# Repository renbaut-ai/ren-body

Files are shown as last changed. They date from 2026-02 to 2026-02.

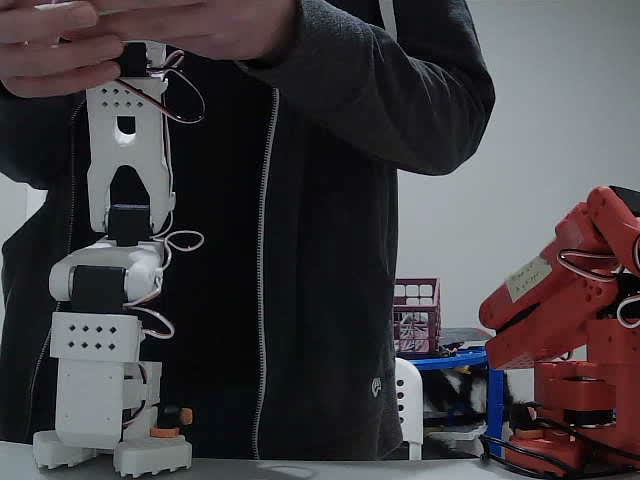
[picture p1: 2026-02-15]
training_data/demos/20260211_171234/frames/frame_0001.jpg

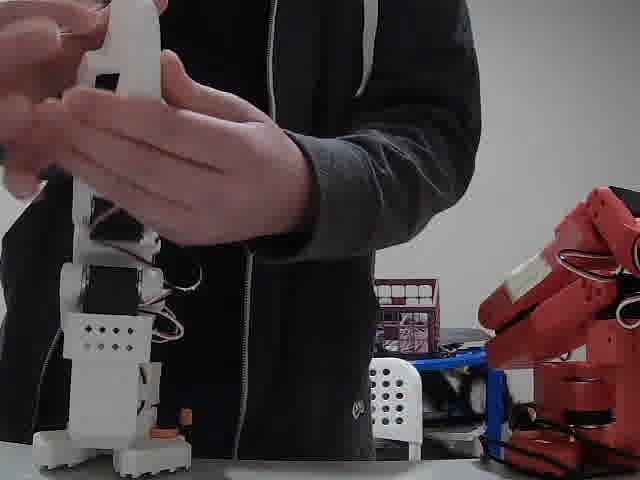
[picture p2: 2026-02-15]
training_data/demos/20260211_171234/frames/frame_0075.jpg

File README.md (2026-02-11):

# Ren Robot Body

Physical robot body design for the Ren AI assistant.

## Design Philosophy

- **Tracked mobile base** for stability and terrain handling (wheels/legs as future upgrade)
- **Articulated upper body** with dual SO-101 arms
- **Sensor head** with stereo depth camera and expression display
- **Mac Mini compute** for running the AI locally

## Quick Start (Blender)

1. Open Blender
2. Go to **Scripting** tab (top menu bar)
3. Click **Open** and select `ren_body_blender.py`
4. Click **Run Script** (▶ button)
5. Switch to **Layout** tab to view model
6. Set viewport shading to **Material Preview** for colors

## Quick Start (FreeCAD)

1. Open FreeCAD
2. Go to **Macro → Macros → Browse** and select `ren_body.py`
3. Run the macro to generate the parametric model
4. Adjust parameters at the top of the script to modify dimensions

## Files

| File | Description |
|---|---|
| `README.md` | This file |
| `PARTS_LIST.md` | Bill of materials with costs |
| `ASSEMBLY_GUIDE.md` | Step-by-step build instructions |
| `ren_body.py` | FreeCAD Python macro for parametric model |
| `ren_body_blender.py` | Blender Python script for 3D model |

## Key Dimensions

| Measurement | Value |
|---|---|
| Total height | 42" (1067mm) |
| Arm shoulder height | 34" (864mm) |
| Base footprint | 350mm × 300mm |
| Shoulder width | 280mm |

## Status

- [x] Initial design concept
- [x] Parts list draft
- [x] Basic FreeCAD model
- [ ] Detailed arm mounts (SO-101 specific)
- [ ] Track system selection
- [ ] Wiring routing
- [ ] Detailed head assembly
- [ ] Printable STL export

## Existing Hardware

- 2× SO-101 arms (marcus_agrippa_follower, marcus_agrippa_leader)
- Bambu A1 for 3D printing
- Mac Mini (planned compute)

---

*Project started: 2026-02-04*

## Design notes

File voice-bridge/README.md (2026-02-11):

# Ren Voice Bridge

Real-time voice communication between a Raspberry Pi (with earbuds) and Ren on the Mac Mini.

## Architecture

```
┌─────────────────────┐         ┌─────────────────────┐
│   Raspberry Pi      │         │     Mac Mini        │
│   (Codec Zero)      │         │                     │
├─────────────────────┤         ├─────────────────────┤
│ • Wired earbuds     │  HTTP   │ • Voice Server      │
│ • PTT button        │ ◄─────► │ • Whisper (STT)     │
│ • Record/Playback   │  :5555  │ • OpenClaw (Ren)    │
│                     │         │ • OpenAI TTS        │
└─────────────────────┘         └─────────────────────┘
```

## Flow

1. User presses PTT button
2. Pi records audio from mic
3. User releases button
4. Pi sends WAV to Mac Mini
5. Mac Mini transcribes with Whisper
6. Mac Mini sends text to OpenClaw (Ren)
7. Ren responds with text
8. Mac Mini converts to speech (OpenAI TTS)
9. Mac Mini sends audio back to Pi
10. Pi plays through earbuds

## Setup - Mac Mini (Server)

```bash
cd server

# Create venv
python3 -m venv .venv
source .venv/bin/activate

# Install deps
pip install -r requirements.txt

# Set OpenAI API key (for TTS)
export OPENAI_API_KEY="your-key"

# Run server
python voice_server.py
```

Server runs on port 5555 by default.

### Environment Variables

- `WHISPER_MODEL` - Whisper model size (tiny/base/small/medium) - default: base
- `OPENCLAW_API` - OpenClaw API endpoint - default: http://localhost:5001
- `TTS_VOICE` - OpenAI TTS voice (alloy/echo/fable/onyx/nova/shimmer) - default: alloy

## Setup - Raspberry Pi Zero

### Hardware

- Raspberry Pi Zero (W or 2W)
- Codec Zero I2S Audio HAT
- Wired earbuds with microphone
- Momentary push button for PTT

### Wiring

| Component | Pi GPIO |
|---|---|
| PTT Button | GPIO17 → GND |
| Status LED (optional) | GPIO27 |

The button uses internal pull-up, so wire between GPIO17 and GND.

### Software Setup

```bash
# Install system deps
sudo apt update
sudo apt install -y python3-pip python3-venv portaudio19-dev

# Clone/copy the pi-client directory
cd pi-client

# Create venv
python3 -m venv .venv
source .venv/bin/activate

# Install deps
pip install -r requirements.txt

# Configure server address
export VOICE_SERVER="http://macmini.local:5555"

# Test audio (record 3 sec and playback)
python voice_client.py --test

# Run client
python voice_client.py
```

### Codec Zero Setup

The Codec Zero HAT should be automatically detected. Configure ALSA:

```bash
# Check if detected
aplay -l
arecord -l

# Test recording
arecord -D default -f S16_LE -r 16000 -c 1 -d 3 test.wav
aplay test.wav
```

### Autostart on Boot

Create `/etc/systemd/system/voice-client.service`:

```ini
[Unit]
Description=Ren Voice Client
After=network.target

[Service]
Type=simple
User=pi
WorkingDirectory=/home/pi/voice-bridge/pi-client
Environment=VOICE_SERVER=http://macmini.local:5555
ExecStart=/home/pi/voice-bridge/pi-client/.venv/bin/python voice_client.py
Restart=always

[Install]
WantedBy=multi-user.target
```

Enable:
```bash
sudo systemctl enable voice-client
sudo systemctl start voice-client
```

## Optimizations for Speed

1. **Whisper model**: Use `tiny` or `base` for fastest transcription
2. **TTS**: OpenAI's `tts-1` is faster than `tts-1-hd`
3. **Network**: Keep Pi and Mac on same LAN, use wired if possible
4. **Audio format**: 16kHz mono WAV is optimal for Whisper

## Troubleshooting

### No audio on Pi
```bash
# Check ALSA devices
aplay -l
arecord -l

# Test with specific device
arecord -D plughw:0,0 -f S16_LE -r 16000 -c 1 -d 3 test.wav
```

### Server not responding
```bash
# Check server health
curl http://macmini.local:5555/health
```

### Slow responses
- Try `WHISPER_MODEL=tiny` for faster transcription
- Check network latency: `ping macmini.local`
- Ensure OpenClaw is running and responsive

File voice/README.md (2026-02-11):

# Ren Voice Interaction

Voice-to-voice conversation system for the Ren robot.

**This is the real deal** — speaks to the actual Ren AI, not placeholder responses!

## Components

1. **Speech-to-Text (STT)**: OpenAI Whisper (local)
2. **Language Model**: OpenClaw Gateway → Ren (Claude)
3. **Text-to-Speech (TTS)**: ElevenLabs via `sag` (Brian voice)

## Setup

### Install Dependencies

```bash
# Audio recording
brew install sox

# Whisper (if not already installed)
brew install openai-whisper

# ElevenLabs TTS (optional but recommended)
brew install steipete/tap/sag

# Python packages (for advanced script)
pip install sounddevice numpy
```

### ElevenLabs Setup

Set your API key:
```bash
export ELEVENLABS_API_KEY="your-key-here"
```

Or add to `~/.zshrc` / `~/.bashrc`.

## Usage

### Main Voice Interface (Recommended)

```bash
cd ~/Projects/ren-body/voice
./ren_voice.sh --loop
```

This connects to the **real Ren** via OpenClaw's API!

Options:
- `--loop` / `-l` — Continuous conversation mode
- `--duration N` / `-d N` — Recording length in seconds (default: 5)
- `--model MODEL` / `-m MODEL` — Whisper model (tiny/base/small/medium)
- `--voice VOICE` / `-v VOICE` — ElevenLabs voice name

### Test Script (Placeholder Responses)

For testing audio pipeline without API:
```bash
./voice_test.sh
```

### Python Version (Advanced)

```bash
python voice_chat.py              # Push-to-talk
python voice_chat.py --continuous # Always listening
python voice_chat.py --wake-word "hey ren"
```

## Files

| File | Description |
|---|---|
| `ren_voice.sh` | **Main script** — real Ren integration |
| `voice_test.sh` | Test script (placeholder responses) |
| `voice_chat.py` | Python version (advanced) |
| `README.md` | This file |

## How the API Works

The `ren_voice.sh` script uses OpenClaw's OpenAI-compatible API:

```bash
curl http://127.0.0.1:18789/v1/chat/completions \
  -H "Authorization: Bearer <token>" \
  -H "x-openclaw-no-tts: true" \
  -d '{"model":"openclaw:main", "messages":[...]}'
```

Key headers:
- `Authorization: Bearer <token>` — Gateway auth
- `x-openclaw-no-tts: true` — Returns text (we do our own TTS)
- `x-openclaw-agent-id: main` — Target Ren agent

## How It Works

```
┌─────────────────────────────────────────────────────────┐
│                    VOICE LOOP                           │
├─────────────────────────────────────────────────────────┤
│                                                         │
│   ┌─────────┐    ┌──────────┐    ┌─────────────────┐   │
│   │   Mic   │───▶│ Whisper  │───▶│ OpenClaw (Ren)  │   │
│   │ (sox)   │    │  (STT)   │    │   thinking...   │   │
│   └─────────┘    └──────────┘    └────────┬────────┘   │
│                                           │             │
│                                           ▼             │
│   ┌─────────┐    ┌──────────┐    ┌─────────────────┐   │
│   │ Speaker │◀───│   sag    │◀───│  Text Response  │   │
│   │         │    │  (TTS)   │    │                 │   │
│   └─────────┘    └──────────┘    └─────────────────┘   │
│                                                         │
└─────────────────────────────────────────────────────────┘
```

## Latency Considerations

For real-time conversation, latency matters:

| Component | Typical Latency | Notes |
|---|---|---|
| Recording | Real-time | - |
| Whisper (base) | 1-3s | Use `tiny` for faster |
| Whisper (turbo) | 0.5-1s | Best balance |
| OpenClaw/Claude | 1-5s | Depends on response length |
| ElevenLabs TTS | 0.5-2s | Streaming available |
| **Total** | **3-10s** | Acceptable for conversation |

### Optimization Tips

1. **Use smaller Whisper model** for faster transcription:
   - `tiny`: Fastest, less accurate
   - `base`: Good balance
   - `turbo`: Best quality/speed ratio

2. **Use ElevenLabs Flash model** for faster TTS:
   ```bash
   sag -m eleven_flash_v2_5 "text"
   ```

3. **Consider streaming** for both STT and TTS (advanced)

## Robot Integration

For the physical robot body:

1. USB microphone array (directional/beamforming)
2. Speaker connected via audio amp
3. This voice loop running continuously
4. Wake word or push-button activation

### Recommended Hardware

- **Mic**: ReSpeaker USB Mic Array ($50-60)
- **Speaker**: 3W+ full range speaker
- **Amp**: MAX98357A or PAM8403

## Troubleshooting

### No audio input
- Check mic is selected: `sox -d -d` (should play back)
- macOS: System Preferences → Security → Microphone

### Whisper errors
- Check model downloaded: `ls ~/.cache/whisper/`
- Try smaller model: `--model tiny`

### sag/TTS issues
- Verify API key: `echo $ELEVENLABS_API_KEY`
- Test directly: `sag "hello"`
- Fallback to `say`: `say "hello"`

---

*Part of the Ren Robot Body project*

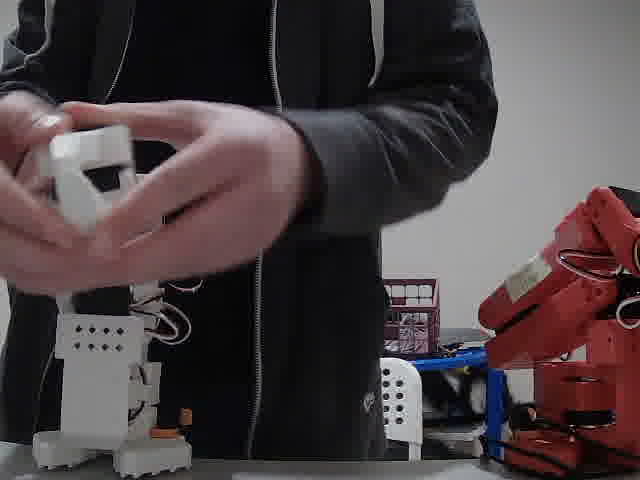
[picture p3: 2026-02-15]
training_data/demos/20260211_171234/frames/frame_0044.jpg

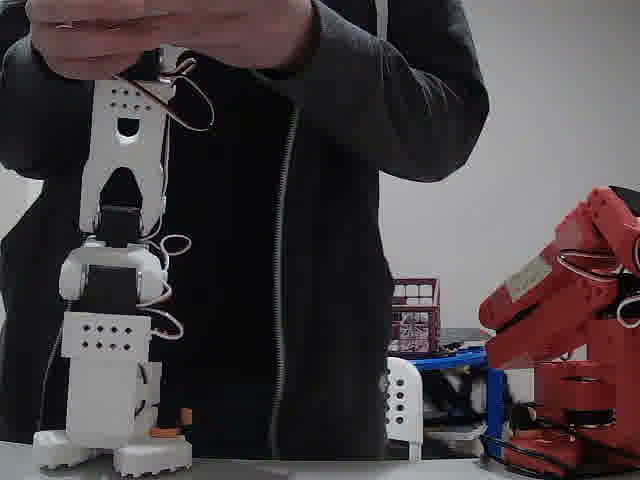
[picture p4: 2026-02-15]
training_data/demos/20260211_171234/frames/frame_0022.jpg

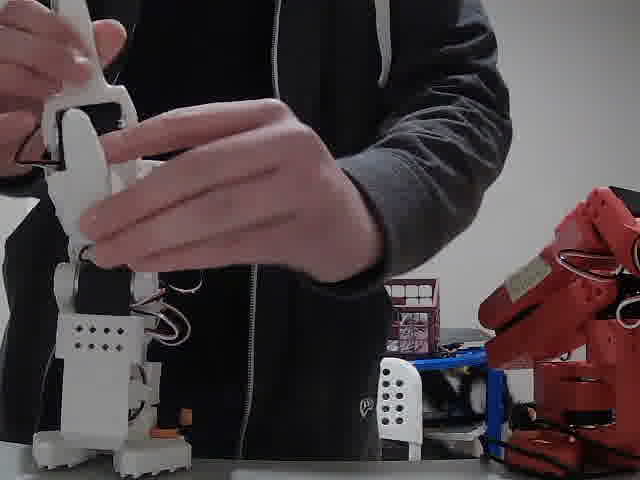
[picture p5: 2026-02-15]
training_data/demos/20260211_171234/frames/frame_0061.jpg

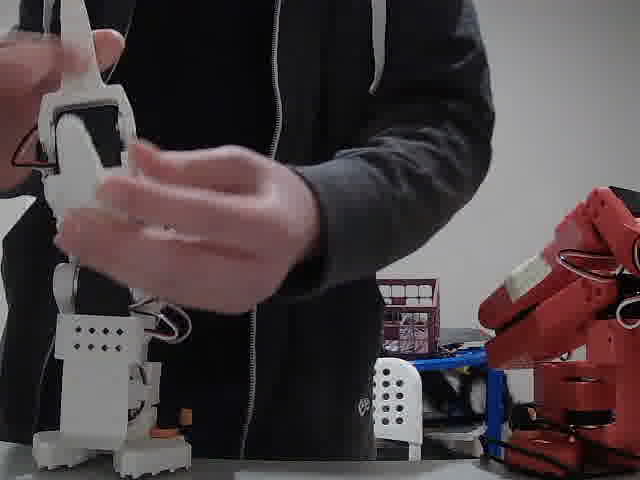
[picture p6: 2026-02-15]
training_data/demos/20260211_171234/frames/frame_0063.jpg

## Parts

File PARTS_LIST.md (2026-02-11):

# Ren Robot Body - Parts List

## Overview
Mobile robot platform with tracked base, articulated torso, dual SO-101 arms, and sensor head.

**Design specs:**
- Arm shoulder height: 34" (864mm) from ground
- Head height: 42" (1067mm) from ground  
- Work surface target: 30" (762mm) tables
- Compute: Mac Mini (M-series)

---

## 1. Mobile Base (Tracked)

### Drive System
| Part | Qty | Est. Cost | Notes |
|---|-----|---|---|
| Tracked chassis kit (ROB-14093 or similar) | 1 | $60-100 | ~300mm wide base, tank-style |
| DC gear motors (12V, 100-200 RPM, encoder) | 2 | $30-50 | Built into some kits |
| Motor driver (L298N or BTS7960) | 1 | $15-25 | Dual H-bridge, 20A+ |
| 12V LiPo battery (5000mAh+) | 1-2 | $40-80 | For drive system |
| Battery voltage monitor/cutoff | 1 | $10 | Protect LiPos |

### Base Structure
| Part | Qty | Est. Cost | Notes |
|---|-----|---|---|
| Aluminum sheet (2-3mm) for base plate | 1 | $20-30 | Or 3D print sections |
| Standoffs, screws, hardware | - | $15 | M3/M4 assortment |

**Base footprint target:** ~350mm L × 300mm W × 100mm H

---

## 2. Torso/Spine Assembly

### Structural
| Part | Qty | Est. Cost | Notes |
|---|-----|---|---|
| 2020 aluminum extrusion (500mm) | 2-3 | $15-25 | Vertical spine structure |
| 2020 corner brackets | 8 | $10 | 90° connections |
| 2020 T-nuts and bolts | Pack | $10 | M5 hardware |
| Shoulder cross-beam (2020 or plate) | 1 | $10 | Mount point for both arms |

**Alternative:** 3D printed spine with internal aluminum rod reinforcement

### Arm Mounting
| Part | Qty | Est. Cost | Notes |
|---|-----|---|---|
| SO-101 arm mounting brackets | 2 | $0 (print) | Custom fit to arm bases |
| Shoulder rotation servos (optional V2) | 2 | $40-60 | Add shoulder yaw DOF |

**Note:** SO-101 arms already owned - base is ~60mm mounting pattern

---

## 3. Head/Sensor Unit

### Pan-Tilt Mount
| Part | Qty | Est. Cost | Notes |
|---|-----|---|---|
| Pan-tilt bracket kit | 1 | $10-20 | SG90/MG90 style |
| MG996R servos (or similar) | 2 | $15-20 | Metal gear, higher torque |

### Cameras
| Part | Qty | Est. Cost | Notes |
|---|-----|---|---|
| OAK-D Lite (stereo depth) | 1 | $150 | Primary vision, depth sensing |
| Wide-angle USB camera (rear) | 1 | $20-30 | 170° FOV situational awareness |

**Alternative primary:** Intel RealSense D435i ($300) or Luxonis OAK-D Pro ($250)

### Face Display
| Part | Qty | Est. Cost | Notes |
|---|-----|---|---|
| 8×8 or 16×16 LED matrix (WS2812/NeoPixel) | 1-2 | $15-25 | Expression display |
| Small OLED (1.3" SSD1306) | 1 | $8-12 | Text/status display |

### Audio
| Part | Qty | Est. Cost | Notes |
|---|-----|---|---|
| Speaker (3W+ full range) | 1 | $10-15 | Voice output |
| Audio amplifier (PAM8403 or MAX98357A) | 1 | $5-10 | I2S or analog |
| USB microphone array (ReSpeaker or similar) | 1 | $30-60 | Directional/beamforming |

**Alternative mic option:** PlayStation Eye camera ($5-10 used) has decent 4-mic array

---

## 4. Compute & Electronics

### Main Computer
| Part | Qty | Est. Cost | Notes |
|---|-----|---|---|
| Mac Mini (already planned) | 1 | - | M2/M3/M4, 16GB+ RAM ideal |
| USB-C hub (powered) | 1 | $30-50 | Expand ports |

### Microcontroller (Low-level control)
| Part | Qty | Est. Cost | Notes |
|---|-----|---|---|
| Arduino Mega or ESP32 | 1 | $15-25 | Motor/servo coordination |
| PCA9685 servo driver | 1 | $8-12 | 16-channel PWM |
| Level shifters | 2 | $5 | 3.3V ↔ 5V |

### Power Distribution
| Part | Qty | Est. Cost | Notes |
|---|-----|---|---|
| 5V regulator (10A+ buck) | 1 | $15 | Servos, logic |
| 12V regulator (if needed) | 1 | $15 | From main battery |
| Power distribution board | 1 | $10 | Clean wiring |
| Main battery (14.8V 4S LiPo, 10000mAh) | 1 | $80-120 | Or 2× smaller in parallel |
| UPS/battery for Mac Mini | 1 | $50-80 | Clean shutdown capability |

---

## 5. Wiring & Connectors

| Part | Qty | Est. Cost | Notes |
|---|-----|---|---|
| XT60 connectors | 10 | $10 | Main power |
| JST-XH connectors (servo) | 20 | $10 | |
| 14-18 AWG silicone wire (red/black) | 5m ea | $15 | Power |
| 22-26 AWG wire (assorted) | 10m | $10 | Signal |
| USB cables (various) | 5 | $20 | Cameras, hub, etc. |
| Heat shrink, cable ties, sleeving | - | $15 | Cable management |

---

## 6. 3D Printed Parts (Filament Cost)

| Part | Est. Filament | Notes |
|---|---|---|
| Base covers/panels | 200g | PLA/PETG |
| Torso covers/cable routing | 150g | |
| Head housing | 100g | |
| Arm mounting brackets | 80g | PETG for strength |
| Camera mounts | 50g | |
| Display bezels | 30g | |
| **Total estimate** | ~600-800g | ~$15-20 in filament |

---

## 7. Existing Parts (Already Have)

| Part | Notes |
|---|---|
| SO-101 Follower arm | marcus_agrippa_follower |
| SO-101 Leader arm (becomes 2nd follower) | marcus_agrippa_leader - may need recalibration |
| Bambu A1 3D printer | For printing body parts |

---

## Cost Summary

| Category | Estimated Cost |
|---|---|
| Mobile Base | $150-250 |
| Torso/Spine | $50-75 |
| Head/Sensors | $200-300 |
| Audio | $45-85 |
| Compute & Electronics | $100-150 |
| Power System | $150-200 |
| Wiring & Misc | $50-80 |
| 3D Printing | $15-20 |
| **Total (excluding Mac Mini)** | **$760-1160** |

---

## Recommended Order of Acquisition

### Phase 1: Core Structure
1. Tracked chassis kit with motors
2. Aluminum extrusion + hardware
3. Motor driver
4. Basic battery for testing

### Phase 2: Sensing
1. OAK-D Lite or depth camera
2. Pan-tilt servos + bracket
3. LED matrix for face

### Phase 3: Integration
1. Power distribution
2. Arduino/ESP32 for low-level control
3. Wiring components
4. Print all structural parts

### Phase 4: Polish
1. Rear camera
2. UPS for Mac Mini
3. Final cable management

---

## Open Questions

- [ ] Exact tracked chassis selection (need stable platform ~15kg capacity)

## Design Decisions (Resolved)

- **Shoulder rotation:** Optional for V1 — SO-101 arms may have enough DOF. Revisit if needed.
- **Audio:** Yes — speaker + mic array for voice interaction
- **Tool holders:** None for V1 — grippers only

---

*Last updated: 2026-02-04*

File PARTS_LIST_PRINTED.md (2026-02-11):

# Ren Robot Body - Parts List (3D Printed Version)

## Overview
Maximizing 3D printed parts, minimizing purchased components.

**Design specs:**
- Arm shoulder height: 34" (864mm) from ground
- Head height: 42" (1067mm) from ground
- Compute: Mac Mini (M-series)
- **Build volume constraint:** Bambu A1 = 256 × 256 × 256 mm

---

## 1. 3D Printed Structure

All printed parts designed modular to fit 256mm build volume.

### Base Chassis
| Part | Qty | Material | Notes |
|---|-----|---|---|
| Base frame sections | 4-6 | PETG (grey) | Bolt together, ~350×300mm assembled |
| Motor mounts | 2 | PETG (grey) | Integrated into base |
| Battery tray | 1 | PETG (grey) | Removable for charging |
| Electronics bay | 1 | PETG (grey) | Mac Mini mount + wiring space |
| Base cover panels | 3-4 | PLA (grey/blue) | Top/sides, cosmetic |
| Ballast mounting plate | 1 | PETG (grey) | Optional, bolt-in weights |

### Drive System (Printed + Purchased)
| Part | Qty | Material | Notes |
|---|-----|---|---|
| Track sprockets/drive wheels | 4-6 | PETG (grey) | Sized to match purchased tracks |
| Sprocket hubs | 2 | PETG (grey) | Motor shaft adapters |
| Idler wheel mounts | 2 | PETG (grey) | Adjustable for track tension |

**Tracks purchased separately** — rubber tank tracks (see Hardware section)

### Torso Frame
| Part | Qty | Material | Notes |
|---|-----|---|---|
| Spine sections | 4 | PETG (grey) | Stack vertically, ~200mm each |
| Spine connectors | 3 | PETG (grey) | Join spine sections |
| Reinforcement rods | 4 | Steel/aluminum rod | 8mm × 800mm, internal to spine |
| Cross braces | 3 | PETG (grey) | Front/rear at different heights |
| Shoulder platform | 2 | PETG (blue) | Left/right halves, accent color |

### Arm Mounts
| Part | Qty | Material | Notes |
|---|-----|---|---|
| Arm mount brackets | 2 | PETG (blue) | SO-101 specific fit |
| Shoulder accent panels | 2 | PLA (blue) | Cosmetic covers |

### Head
| Part | Qty | Material | Notes |
|---|-----|---|---|
| Head shell (front) | 1 | PETG (white) | Face with display cutout |
| Head shell (rear) | 1 | PETG (grey) | Camera mount integrated |
| Display bezel | 1 | PLA (white) | Frame for LED matrix |
| Eye surrounds | 2 | PLA (red) | Camera accent rings |
| Neck tube | 1 | PETG (grey) | Or aluminum tube |
| Pan-tilt mount | 1 | PETG (grey) | Servo bracket |

### Cable Management
| Part | Qty | Material | Notes |
|---|-----|---|---|
| Cable clips | 20+ | PLA (grey) | Snap-fit to frame |
| Wire channels | 6 | PLA (grey) | Route through spine |

---

## 2. Filament & Color Scheme

**Available:** Grey (full), Blue (full), White (~7/8), Red (~7/8)

| Color | Use | Est. Amount |
|---|-----|---|
| **Grey** | Base frame, spine, motor mounts, structural | ~1.5-2 kg |
| **Blue** | Arm mounts, shoulder plates, accent panels | ~0.5-0.7 kg |
| **White** | Head shell, face area, display bezel | ~0.3-0.4 kg |
| **Red** | Status indicators, small accents, highlights | ~0.1 kg |
| **Total** | | **~2.5-3.2 kg** |

**Color vibe:** Industrial grey chassis, blue accents on upper body, white face for contrast, red pops for personality.

*No new filament purchase needed if current spools have enough.*

---

## 3. Hardware (Must Buy)

### Drive System
| Part | Qty | Est. Cost | Notes |
|---|-----|---|---|
| DC gear motors (12V, 100-200 RPM, encoder) | 2 | $25-40 | 25mm gearbox style |
| Motor driver (L298N or BTS7960) | 1 | $10-20 | |
| Rubber tank tracks | 2 | $20-40 | Match to sprocket size (e.g., 60mm-80mm width) |

### Reinforcement
| Part | Qty | Est. Cost | Notes |
|---|-----|---|---|
| Steel/aluminum rods (8mm × 1m) | 4 | $15-20 | Cut to length |
| Threaded inserts (M3) | 50 | $8 | Heat-set brass inserts |
| Threaded inserts (M4) | 20 | $5 | For larger bolts |
| Bolts/nuts assortment (M3, M4) | 1 kit | $15 | |

### Head/Sensors
| Part | Qty | Est. Cost | Notes |
|---|-----|---|---|
| OAK-D Lite (stereo depth) | 1 | $150 | Primary vision |
| Wide-angle USB camera | 1 | $20-30 | Rear awareness |
| MG996R servos (pan-tilt) | 2 | $15-20 | |
| 8×8 or 16×16 LED matrix | 1 | $15-20 | Face display |

### Audio
| Part | Qty | Est. Cost | Notes |
|---|-----|---|---|
| Speaker (3W+) | 1 | $10-15 | |
| Amplifier board | 1 | $5-10 | |
| USB mic array | 1 | $30-60 | Or PS Eye $5-10 |

### Electronics
| Part | Qty | Est. Cost | Notes |
|---|-----|---|---|
| Arduino Mega or ESP32 | 1 | $15-25 | Low-level control |
| PCA9685 servo driver | 1 | $8-12 | |
| USB hub (powered) | 1 | $30 | |
| Level shifters | 2 | $5 | |

### Power
| Part | Qty | Est. Cost | Notes |
|---|-----|---|---|
| 12V LiPo (5000mAh+) | 1-2 | $40-60 | Drive + logic |
| 5V buck converter (10A) | 1 | $12-15 | |
| XT60 connectors | 6 | $8 | |
| Power switch | 1 | $5 | |
| Voltage monitor | 1 | $5 | |

### Wiring
| Part | Qty | Est. Cost | Notes |
|---|-----|---|---|
| Silicone wire (14-22 AWG) | - | $15 | Assorted |
| Connectors (JST, Dupont) | - | $10 | |
| Heat shrink | - | $5 | |

---

## 4. Existing Parts (Already Have)

| Part | Notes |
|---|---|
| SO-101 arms (×2) | Left + Right arms |
| Bambu A1 printer | For all printed parts |
| Mac Mini (planned) | Main compute |

---

## 5. Cost Summary (Printed Version)

| Category | Estimated Cost |
|---|---|
| 3D Printing (filament) | $0* |
| Drive system (motors + tracks) | $55-100 |
| Reinforcement hardware | $45-50 |
| Head/Sensors | $200-280 |
| Audio | $45-85 |
| Electronics | $60-75 |
| Power system | $70-95 |
| Wiring | $30 |
| **Total (excluding Mac Mini)** | **$505-715** |

*\*Using existing filament supply*

**Savings vs aluminum frame version:** ~$250-450

---

## 6. Print Time Estimate

| Category | Est. Print Time |
|---|---|
| Base sections | 20-30 hours |
| Torso/spine | 25-35 hours |
| Head | 8-12 hours |
| Mounts & brackets | 10-15 hours |
| Covers & cosmetic | 10-15 hours |
| **Total** | **~75-110 hours** |

(Split across multiple prints over 1-2 weeks)

---

## 7. Design Priorities for Printability

1. **Modular sections** — nothing larger than 250mm in any dimension
2. **Minimal supports** — orient parts to print flat where possible
3. **Bolt-together assembly** — heat-set inserts for repeated disassembly
4. **Rod reinforcement** — vertical spine needs internal metal rods
5. **Parametric design** — easy to adjust if fit is off

---

## 8. Design Notes

**Ballast:** Optional mounting points included in base design. Mac Mini (~1.2kg) + motors (~0.5kg) + battery (~0.5-1kg) = ~2.5-3.5kg low in the chassis should provide decent stability. Can add lead weights or steel plates later if tippy.

**Resolved:**
- ✅ Tracks: Rubber (purchased), not printed
- ✅ Colors: Grey primary, blue accent, white face, red highlights
- ✅ Ballast: Mount points included, probably not needed initially

---

*Last updated: 2026-02-04*

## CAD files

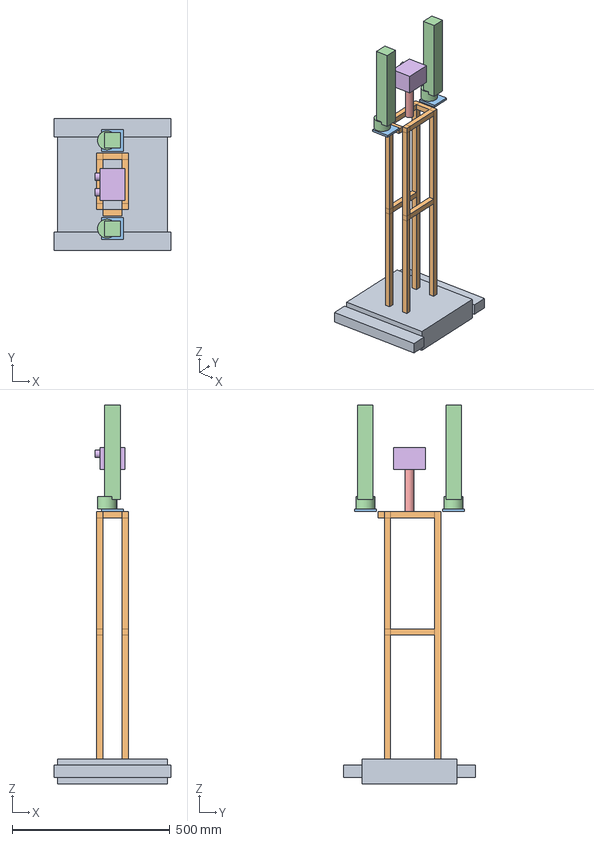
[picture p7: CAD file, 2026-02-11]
RenBody.FCStd
370.0 x 420.0 x 1202.0 mm
Base_Assembly
Torso_Frame
Arm_Mounts
Arms_Placeholder
Neck
Head
MacMini_Placeholder

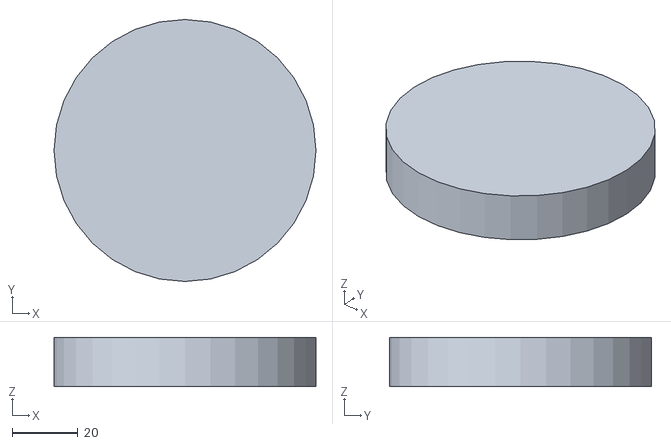
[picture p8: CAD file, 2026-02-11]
stl/Sprocket_Left_Front.stl
80.0 x 80.0 x 15.0

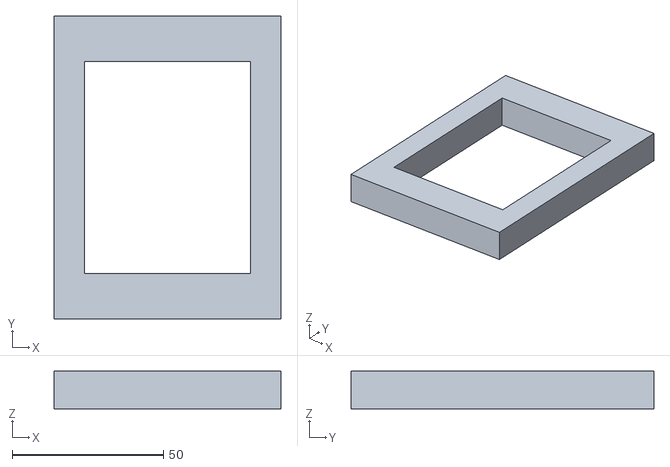
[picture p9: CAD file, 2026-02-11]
stl_detailed/Cross_Brace_Mid_Detailed.stl
75.0 x 100.0 x 12.5

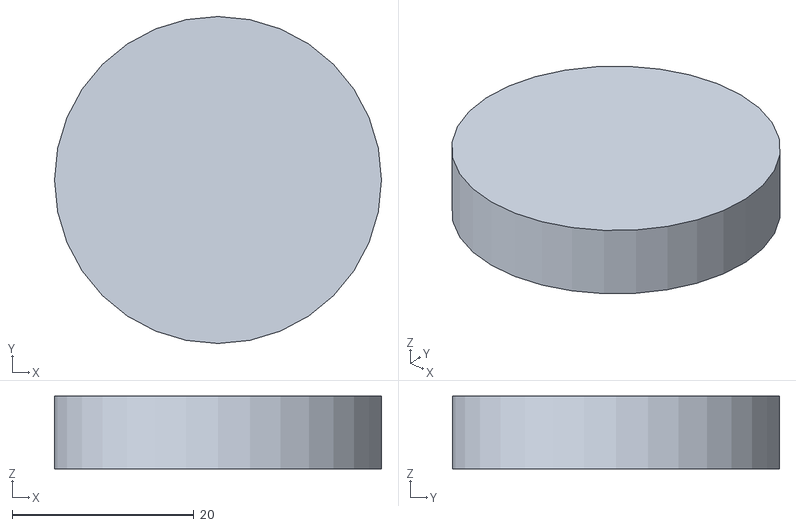
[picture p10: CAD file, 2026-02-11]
stl/Eye_Ring_Left.stl
36.0 x 36.0 x 8.00

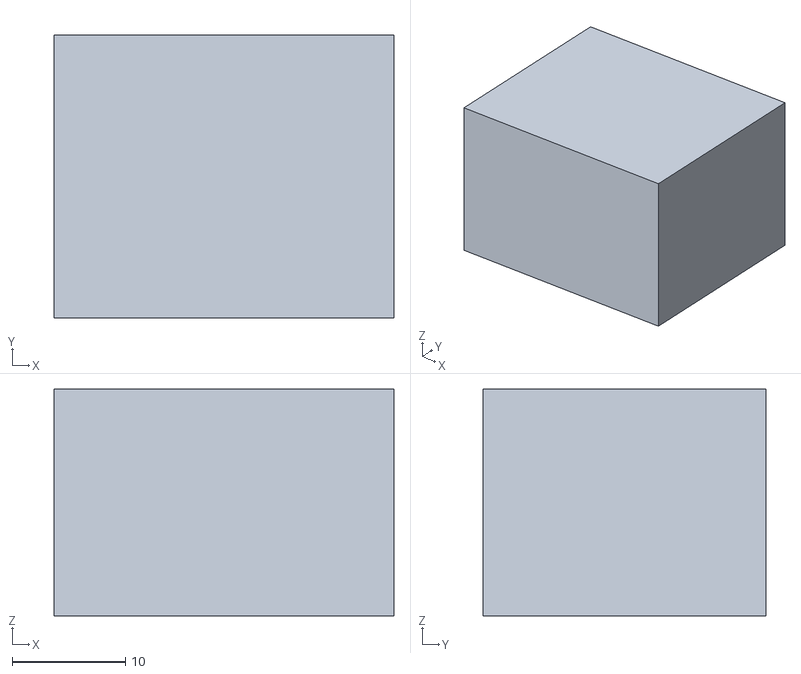
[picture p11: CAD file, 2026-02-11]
stl/Motor_Mount_Left.stl
30.0 x 25.0 x 20.0

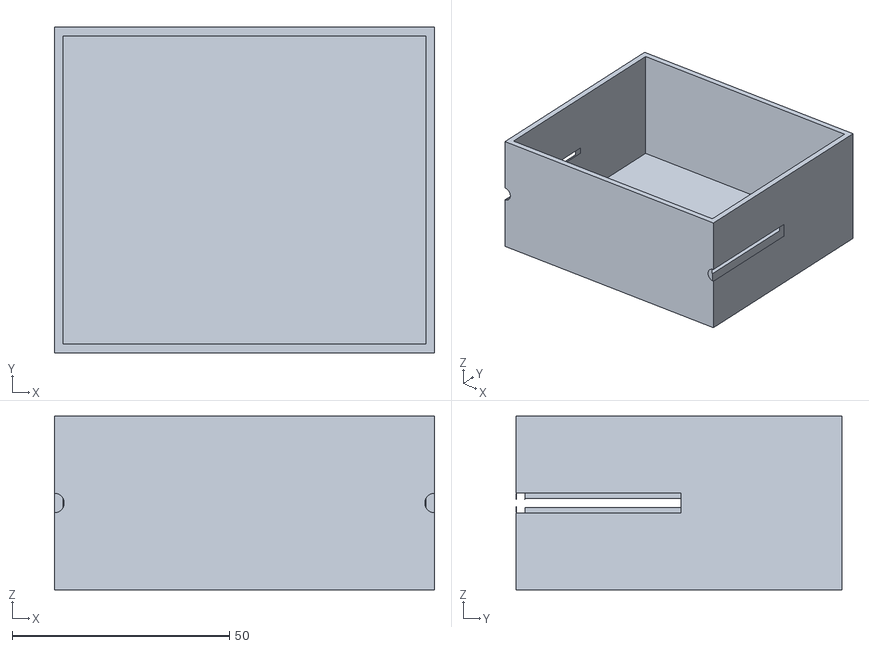
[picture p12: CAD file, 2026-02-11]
stl_detailed/Base_Section_4_Detailed.stl
87.5 x 75.0 x 40.0

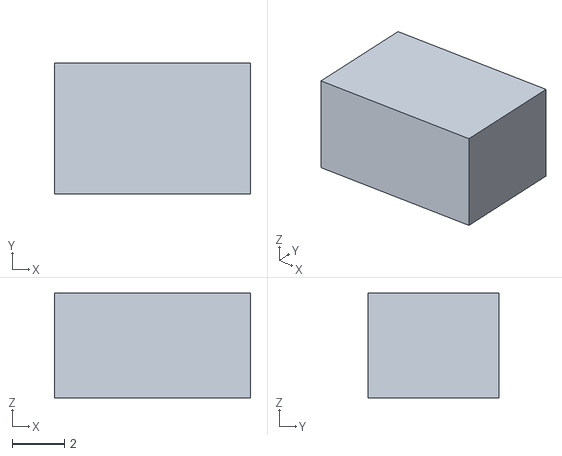
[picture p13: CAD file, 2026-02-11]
stl/Cable_Clip_9.stl
7.50 x 5.00 x 4.00

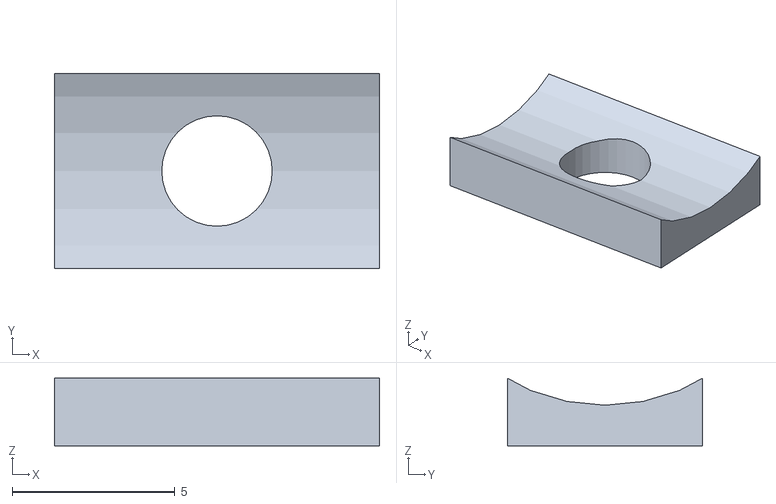
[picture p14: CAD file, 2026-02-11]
stl_detailed/Cable_Clip_1_Detailed.stl
10.0 x 6.00 x 2.08

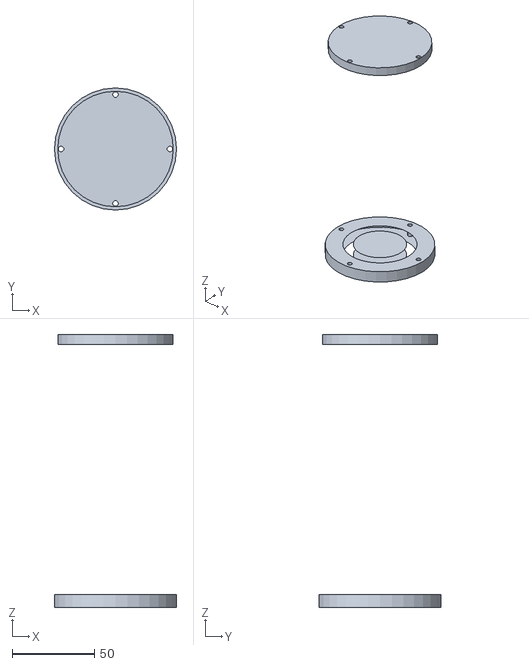
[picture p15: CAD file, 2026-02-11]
stl_detailed/Neck_Detailed.stl
74.0 x 74.0 x 165.5

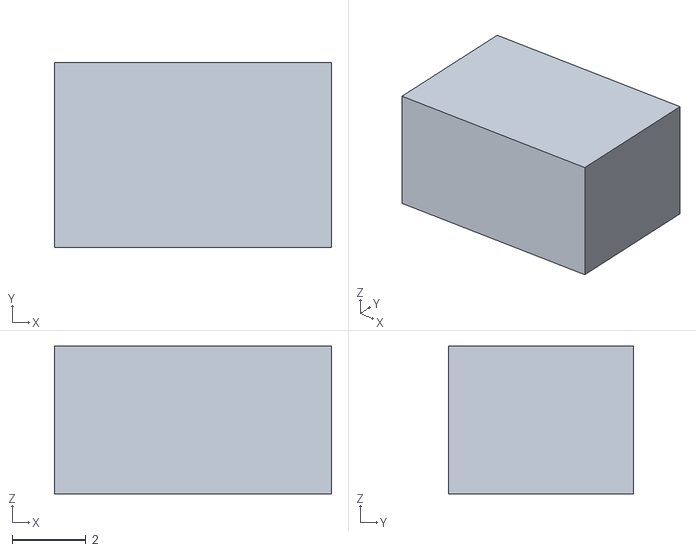
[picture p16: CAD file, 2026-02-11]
stl/Cable_Clip_1.stl
7.50 x 5.00 x 4.00

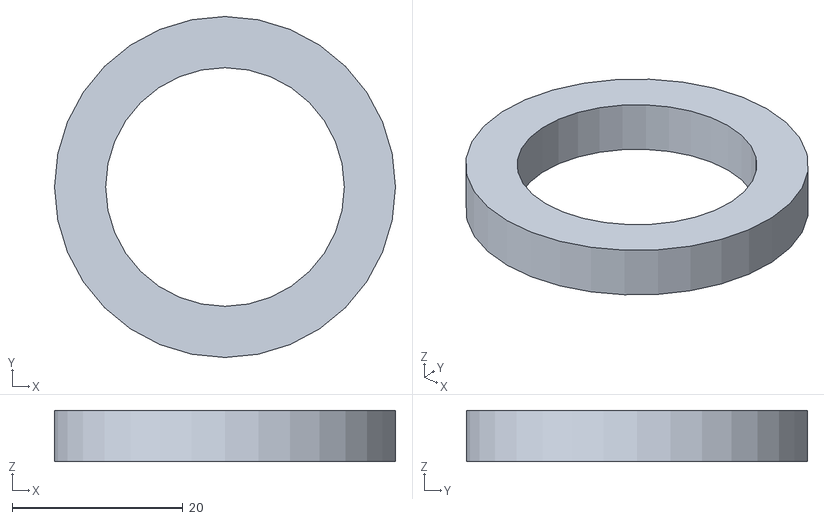
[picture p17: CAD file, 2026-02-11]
stl_detailed/Eye_Ring_Left_Detailed.stl
40.0 x 40.0 x 6.00

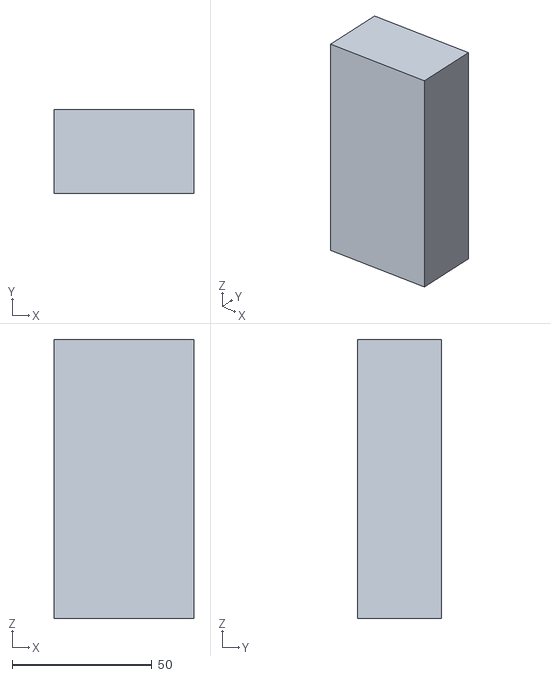
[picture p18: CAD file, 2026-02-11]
stl/Spine_Section_1.stl
50.0 x 30.0 x 100.0

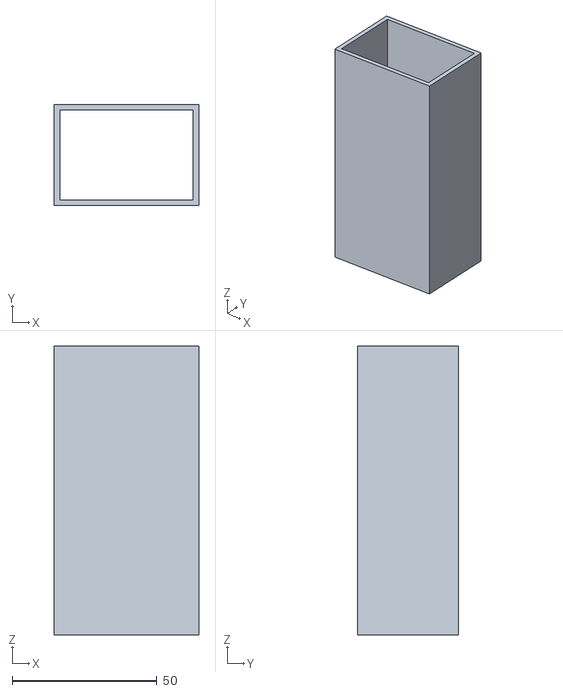
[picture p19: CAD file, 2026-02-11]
stl_detailed/Spine_Section_1_Detailed.stl
50.0 x 35.0 x 100.0

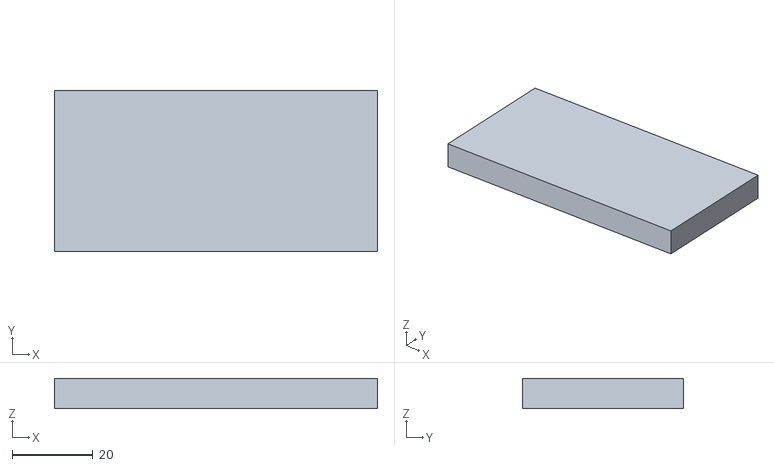
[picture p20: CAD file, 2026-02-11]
stl/Shoulder_Plate_Left.stl
80.0 x 40.0 x 7.50

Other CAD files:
stl_detailed/Cross_Brace_Upper_Detailed.stl
stl/Eye_Ring_Right.stl
stl_detailed/Head_Front_Detailed.stl
stl/Cable_Clip_4.stl
stl/Arm_Mount_Left.stl
stl/Arm_Mount_Right.stl
stl/Base_Section_1.stl
stl/Base_Section_2.stl
stl/Base_Section_3.stl
stl/Base_Section_4.stl
stl/Cable_Clip_10.stl
stl/Cable_Clip_2.stl
stl/Cable_Clip_3.stl
stl/Cable_Clip_5.stl
stl/Cable_Clip_6.stl
stl/Cable_Clip_7.stl
stl/Cable_Clip_8.stl
stl/Cross_Brace_Lower.stl
stl/Cross_Brace_Mid.stl
stl/Cross_Brace_Upper.stl
stl/Display_Bezel.stl
stl/Head_Front_Shell.stl
stl/Head_Rear_Shell.stl
stl/Idler_Tensioner_Left.stl
stl/Idler_Tensioner_Right.stl
stl/Motor_Mount_Right.stl
stl/Neck_Tube.stl
stl/Pan_Tilt_Arm.stl
stl/Pan_Tilt_Base.stl
stl/Shoulder_Plate_Right.stl
stl/Spine_Connector_1.stl
stl/Spine_Connector_2.stl
stl/Spine_Connector_3.stl
stl/Spine_Section_2.stl
stl/Spine_Section_3.stl
stl/Spine_Section_4.stl
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

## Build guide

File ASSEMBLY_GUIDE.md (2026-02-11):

# Ren Robot Body - Assembly Guide (3D Printed Version)

A step-by-step guide to printing and assembling the Ren robot body.

---

## Table of Contents
1. [Tools & Supplies Required](#tools--supplies-required)
2. [Printing Overview](#printing-overview)
3. [Phase 1: Print All Parts](#phase-1-print-all-parts)
4. [Phase 2: Post-Processing](#phase-2-post-processing)
5. [Phase 3: Base Assembly](#phase-3-base-assembly)
6. [Phase 4: Spine Assembly](#phase-4-spine-assembly)
7. [Phase 5: Shoulder & Arm Installation](#phase-5-shoulder--arm-installation)
8. [Phase 6: Head Assembly](#phase-6-head-assembly)
9. [Phase 7: Electronics & Wiring](#phase-7-electronics--wiring)
10. [Phase 8: Software Setup](#phase-8-software-setup)
11. [Testing & Calibration](#testing--calibration)
12. [Troubleshooting](#troubleshooting)

---

## Tools & Supplies Required

### Printing
- [ ] Bambu A1 (or similar, 256mm+ build volume)
- [ ] Filament: Grey PETG (~2kg), Blue PETG (~0.7kg), White PETG (~0.4kg), Red PLA (~0.1kg)
- [ ] Painter's tape or glue stick (bed adhesion)
- [ ] Flush cutters (support removal)

### Assembly Tools
- [ ] Metric hex key set (2mm, 2.5mm, 3mm, 4mm)
- [ ] Phillips screwdrivers (#0, #1, #2)
- [ ] Soldering iron (for heat-set inserts AND electronics)
- [ ] Heat-set insert tips (M3, M4)
- [ ] Wire strippers
- [ ] Multimeter
- [ ] Calipers

### Finishing Tools
- [ ] Sandpaper (120, 220, 400 grit)
- [ ] Files (flat, round)
- [ ] Deburring tool
- [ ] Heat gun (optional, for minor warping fixes)

### Safety
- [ ] Safety glasses
- [ ] Work gloves
- [ ] Ventilation (soldering/printing)
- [ ] ESD wrist strap (electronics)

### Consumables
- [ ] Heat-set inserts: M3 × 50, M4 × 20
- [ ] Bolts: M3×8, M3×12, M3×20, M4×12, M4×20 (assorted)
- [ ] Locknuts: M3, M4
- [ ] CA glue (super glue)
- [ ] Epoxy (structural bonding)
- [ ] Thread locker (blue Loctite)

---

## Printing Overview

### Print Settings by Material

| Material | Nozzle | Bed | Speed | Notes |
|---|---|-----|---|---|
| PETG (structural) | 240-250°C | 80°C | 50-60mm/s | Enclosure helps |
| PLA (accents) | 200-210°C | 60°C | 60-80mm/s | Easy, fast |

### General Settings (All Parts)
- **Layer height:** 0.2mm (0.16mm for fine detail)
- **Walls:** 4 perimeters
- **Infill:** 40% (structural), 20% (covers/cosmetic)
- **Infill pattern:** Gyroid or Grid
- **Supports:** As needed (avoid where possible through orientation)
- **Brim:** Recommended for large flat parts

### Part Orientation Guidelines
- Print large flat faces DOWN
- Orient for minimal supports
- Holes/threads should be vertical where possible
- Long parts print standing up if they fit

---

## Phase 1: Print All Parts

**Total estimated print time: 75-110 hours**

Print in the order below — earlier batches can be post-processed while later ones print.

### Batch 1: Base Frame (Grey PETG) — ~20-25 hours

| Part | Qty | Est. Time | Orientation | Notes |
|---|-----|---|---|---|
| Base_Section_1 | 1 | 5h | Flat | Add heat-set insert holes |
| Base_Section_2 | 1 | 5h | Flat | Mirror of section 1 |
| Base_Section_3 | 1 | 5h | Flat | |
| Base_Section_4 | 1 | 5h | Flat | |
| Ballast_Mount | 1 | 1h | Flat | Optional |

**Check before printing:**
- [ ] Motor mount holes sized correctly
- [ ] Bolt pattern matches between sections
- [ ] Battery tray fits your battery

### Batch 2: Drive System (Grey PETG) — ~8-10 hours

| Part | Qty | Est. Time | Orientation | Notes |
|---|-----|---|---|---|
| Sprocket_Left_Front | 1 | 1.5h | Flat (axle vertical) | |
| Sprocket_Left_Rear | 1 | 1.5h | Flat | |
| Sprocket_Right_Front | 1 | 1.5h | Flat | |
| Sprocket_Right_Rear | 1 | 1.5h | Flat | |
| Motor_Mount_Left | 1 | 1h | Flat | |
| Motor_Mount_Right | 1 | 1h | Flat | |
| Idler_Tensioner × 2 | 2 | 1h | Flat | Track tension adjustment |

**Important:** Measure your purchased rubber tracks FIRST! Sprocket diameter must match track pitch.

### Batch 3: Spine Sections (Grey PETG) — ~25-30 hours

| Part | Qty | Est. Time | Orientation | Notes |
|---|-----|---|---|---|
| Spine_Section_1 | 1 | 6h | Standing | Rod channels must align |
| Spine_Section_2 | 1 | 6h | Standing | |
| Spine_Section_3 | 1 | 6h | Standing | |
| Spine_Section_4 | 1 | 6h | Standing | Top section |
| Spine_Connector × 3 | 3 | 2h | Flat | Joins spine sections |
| Cross_Brace_Lower | 1 | 1.5h | Flat | |
| Cross_Brace_Mid | 1 | 1.5h | Flat | |
| Cross_Brace_Upper | 1 | 1.5h | Flat | |

### Batch 4: Shoulders (Blue PETG) — ~6-8 hours

| Part | Qty | Est. Time | Orientation | Notes |
|---|-----|---|---|---|
| Shoulder_Plate_Left | 1 | 2h | Flat | |
| Shoulder_Plate_Right | 1 | 2h | Flat | |
| Arm_Mount_Left | 1 | 1.5h | Flat | SO-101 specific fit |
| Arm_Mount_Right | 1 | 1.5h | Flat | Test fit before full print |

**Test fit:** Print a small test piece with the SO-101 mounting pattern first!

### Batch 5: Head - White Parts (White PETG) — ~4-5 hours

| Part | Qty | Est. Time | Orientation | Notes |
|---|-----|---|---|---|
| Head_Front_Shell | 1 | 3h | Face down | Display cutout |
| Display_Bezel | 1 | 1h | Flat | Frames LED matrix |

### Batch 6: Head - Grey Parts (Grey PETG) — ~5-7 hours

| Part | Qty | Est. Time | Orientation | Notes |
|---|-----|---|---|---|
| Head_Rear_Shell | 1 | 3h | Flat | Camera mount holes |
| Neck_Tube | 1 | 2h | Standing | Consider aluminum tube instead |
| Pan_Tilt_Base | 1 | 1h | Flat | Servo mount |
| Pan_Tilt_Arm | 1 | 0.5h | Flat | |

### Batch 7: Accents (Red PLA) — ~2 hours

| Part | Qty | Est. Time | Orientation | Notes |
|---|-----|---|---|---|
| Eye_Ring_Left | 1 | 0.5h | Flat | |
| Eye_Ring_Right | 1 | 0.5h | Flat | |
| Status_Indicator | 1 | 0.25h | Flat | Chest light |
| Cable_Clips × 20 | 20 | 1h | Flat (batch) | Snap-fit |

### Batch 8: Miscellaneous (Grey PLA/PETG) — ~5 hours

| Part | Qty | Est. Time | Orientation | Notes |
|---|-----|---|---|---|
| Cable_Channels × 6 | 6 | 2h | Flat | Wire routing |
| Electronics_Tray | 1 | 2h | Flat | Arduino/driver mount |
| Battery_Strap_Mounts × 2 | 2 | 0.5h | Flat | Velcro strap anchors |
| Misc covers/panels | - | 1h | Flat | As needed |

---

## Phase 2: Post-Processing

### For All Printed Parts

1. **Remove supports** carefully with flush cutters
2. **Clean up stringing** with heat gun (quick pass) or blade
3. **Sand mating surfaces** with 220 grit for better fit
4. **Test fit** parts together before installing inserts
5. **Check hole sizes** with calipers — drill out if undersized

### Installing Heat-Set Inserts

**Tools needed:** Soldering iron with heat-set tip, or plain iron (slower)

**Temperature:** ~220-250°C for PETG

**Technique:**
1. Place insert on hole (don't force)
2. Apply gentle pressure with hot iron
3. Let insert sink in slowly (5-10 seconds)
4. Stop when insert is ~0.5mm below surface
5. Let cool completely before use

**Insert locations:**

| Part | Insert Size | Qty | Purpose |
|---|---|-----|---|
| Base sections | M4 | 16 | Join sections together |
| Base sections | M3 | 8 | Motor mount |
| Spine sections | M3 | 24 | Connectors + braces |
| Shoulder plates | M4 | 8 | Attach to spine |
| Arm mounts | M3 | 8 | SO-101 attachment |
| Head shells | M3 | 12 | Head assembly |

### Installing Reinforcement Rods

The spine requires 4 steel/aluminum rods (8mm × ~800mm) for rigidity.

1. **Dry fit** all spine sections to check alignment
2. **Insert rods** through bottom section first
3. **Add sections** one at a time, threading onto rods
4. Rods should extend into shoulder platform
5. **Secure** with set screws or epoxy at top/bottom

---

## Phase 3: Base Assembly

**Time estimate:** 2-3 hours

### Step 3.1: Prepare Base Sections

1. Install all heat-set inserts in base sections
2. Dry fit sections together to check alignment
3. Sand mating edges if needed

### Step 3.2: Assemble Base Frame

1. Place sections on flat surface
2. Align bolt holes carefully
3. Insert M4 bolts through sections
4. Tighten gradually in cross pattern (don't overtighten!)
5. Check frame is flat (no rocking)

### Step 3.3: Install Motor Mounts

1. Position motor mounts inside base
2. Align with sprocket positions
3. Bolt down with M3 hardware
4. **Do not install motors yet** — easier to wire first

### Step 3.4: Install Sprockets & Idlers

1. Mount rear idler wheels on tensioner assemblies
2. Install tensioners in base (adjustable position)
3. Mount front drive sprockets (connect to motor shafts later)
4. Verify wheels spin freely

### Step 3.5: Track Installation

1. Loop rubber track around sprockets
2. Adjust idler position until track is snug
3. Track should deflect ~10mm when pressed
4. Lock idler position
5. Repeat for second track

### Step 3.6: Install Motors

1. Slide motors into mounts
2. Align motor shaft with drive sprocket
3. Secure with set screw or coupling
4. Wire motor leads (label L+, L-, R+, R-)
5. Test spin direction (both should drive forward)

**⚠️ CHECKPOINT:** 
- [ ] Tracks move smoothly
- [ ] No binding or rubbing
- [ ] Motors spin correct direction

---

## Phase 4: Spine Assembly

**Time estimate:** 2-3 hours

### Step 4.1: Prepare Spine Sections

1. Install heat-set inserts
2. Check rod holes are clear (drill if needed)
3. Dry fit all sections to verify alignment

### Step 4.2: Pre-Install Wiring Channels

Before assembling spine, install internal cable routing:

1. Position cable channels inside spine sections
2. Fish pull-strings through for later wiring
3. Leave strings accessible at top and bottom

### Step 4.3: Assemble Spine

1. Start with bottom spine section
2. Insert reinforcement rods from bottom
3. Add spine connector
4. Stack next section, threading onto rods
5. Repeat for all sections
6. Tighten connector bolts progressively

### Step 4.4: Attach Cross Braces

1. Install lower brace (~50mm above base)
2. Install mid brace (middle of spine)
3. Install upper brace (just below shoulders)
4. Verify spine is straight and square

### Step 4.5: Mount Spine to Base

1. Position spine on base center
2. Align mounting holes
3. Bolt down with M4 hardware
4. Check spine is vertical (use level)
5. Apply thread locker to base bolts

**⚠️ CHECKPOINT:**
- [ ] Spine is vertical
- [ ] No wobble or flex
- [ ] Cable routing accessible

---

## Phase 5: Shoulder & Arm Installation

**Time estimate:** 1.5-2 hours

### Step 5.1: Attach Shoulder Plates

1. Position shoulder plates on top of spine
2. Align with reinforcement rod holes
3. Rod ends should seat into shoulder pockets
4. Bolt down shoulders to upper spine section
5. Verify shoulders are level

### Step 5.2: Install Arm Mounts

1. Attach arm mount brackets to shoulder plates
2. Position for correct arm spacing (280mm center-to-center)
3. Tighten bolts but leave slightly loose for adjustment

### Step 5.3: Mount SO-101 Arms

⚠️ **Power off arms before handling**

1. Position left arm on left mount
2. Align mounting holes
3. Secure with M3 bolts (don't overtighten - plastic threads!)
4. Repeat for right arm
5. Verify both arms are level and parallel

### Step 5.4: Route Arm Cables

1. Bundle each arm's cables together
2. Route down through spine interior
3. Use cable clips on cross braces
4. Leave service loop at arm base
5. Label cables: ARM_L, ARM_R

### Step 5.5: Final Arm Mount Adjustment

1. Power on arms briefly
2. Home both arms
3. Check for collision with body/shoulders
4. Adjust mount position if needed
5. Final tighten all bolts

**⚠️ CHECKPOINT:**
- [ ] Arms securely mounted
- [ ] Arms home without collision
- [ ] Cables routed cleanly

---

## Phase 6: Head Assembly

**Time estimate:** 2-3 hours

### Step 6.1: Pan-Tilt Mechanism

1. Assemble pan servo into base mount
2. Attach tilt bracket to pan servo horn
3. Install tilt servo
4. Test movement by hand (no power)
5. Mount assembly to top of neck

### Step 6.2: Mount Neck to Shoulders

1. Position neck tube on shoulder center
2. Bolt down with M3 hardware
3. Route servo wires down through neck
4. Verify neck is vertical

### Step 6.3: Install Cameras

**OAK-D Lite (front):**
1. Mount camera to head front shell interior
2. Position lenses to align with eye holes
3. Secure with M2/M2.5 screws
4. Route USB-C down

**Rear Camera:**
1. Mount to head rear shell
2. Angle slightly down (~15°)
3. Route USB cable

### Step 6.4: Install Face Display

1. Position LED matrix behind display cutout
2. Attach with small dabs of hot glue or mounting tape
3. Connect data + power wires
4. Install display bezel over matrix

### Step 6.5: Install Audio (Speaker + Mic)

1. Mount speaker inside head (facing forward or down)
2. Connect to amplifier board
3. Mount mic array (position for best pickup)
4. Route all audio wires down through neck

### Step 6.6: Install Eye Rings

1. Press-fit or glue red eye rings around camera lenses
2. Should frame the cameras visually

### Step 6.7: Assemble Head Shells

1. Connect front and rear head shells
2. Secure with M3 bolts
3. Verify all cameras and display visible
4. Check no wires pinched

### Step 6.8: Mount Head to Pan-Tilt

1. Attach head assembly to tilt mechanism
2. Balance head (should not droop when unpowered)
3. Test pan-tilt movement range
4. Adjust stops if needed to prevent wire strain

**⚠️ CHECKPOINT:**
- [ ] Pan-tilt moves smoothly
- [ ] All cameras have clear view
- [ ] Display visible
- [ ] No wires pinched

---

## Phase 7: Electronics & Wiring

**Time estimate:** 3-4 hours

### Step 7.1: System Wiring Diagram

```
MAIN BATTERY (12V LiPo)
    │
    ├─► Main Switch
    │       │
    │       ├─► Motor Driver ───► Left Motor
    │       │                 ───► Right Motor
    │       │
    │       └─► 5V Buck Converter (10A)
    │               │
    │               ├─► Arduino/ESP32
    │               ├─► Servo Power (pan-tilt)
    │               ├─► LED Matrix
    │               └─► Audio Amp
    │
    └─► Voltage Monitor (display)

MAC MINI (separate power, USB-C)
    │
    └─► USB Hub
            ├─► Left Arm (USB)
            ├─► Right Arm (USB)
            ├─► OAK-D Lite (USB 3.0)
            ├─► Rear Camera (USB 2.0)
            ├─► USB Mic Array
            └─► Arduino/ESP32 (serial)
```

### Step 7.2: Mount Electronics in Base

1. Install electronics tray in base
2. Mount motor driver (with standoffs for cooling)
3. Mount buck converters
4. Mount Arduino/ESP32
5. Position Mac Mini in designated bay

### Step 7.3: Power Wiring

1. **Main battery leads** → Switch → Distribution
2. **Motor driver power** (12V from switch)
3. **Buck converter input** (12V from switch)
4. **5V distribution** to all logic components
5. **Add fuses:** 20A on motors, 10A on 5V rail

### Step 7.4: Motor Wiring

1. Motor leads to driver outputs
   - Left motor → M1A, M1B
   - Right motor → M2A, M2B
2. Driver control pins to Arduino PWM outputs
3. Encoder wires (if equipped) to Arduino interrupt pins

### Step 7.5: Servo Wiring

1. Pan servo signal → Arduino PWM pin (or PCA9685)
2. Tilt servo signal → Arduino PWM pin
3. Servo power from 5V rail (shared ground!)

### Step 7.6: Display Wiring

1. LED matrix data → Arduino digital pin
2. LED matrix power → 5V rail (check current draw!)
3. May need separate 5V supply if >2A draw

### Step 7.7: Audio Wiring

1. Amplifier input from Mac Mini audio jack (or USB DAC)
2. Amplifier power from 5V rail
3. Speaker to amplifier output
4. USB mic to USB hub

### Step 7.8: USB Connections

1. Connect powered USB hub to Mac Mini
2. Plug in all USB devices:
   - Both arm controllers
   - OAK-D Lite (use USB 3.0 port!)
   - Rear camera
   - Mic array
   - Arduino (serial)

### Step 7.9: Wire Management

1. Label every wire at both ends
2. Bundle related wires together
3. Route cleanly through spine
4. Secure with clips and velcro
5. Leave service loops for maintenance
6. Verify no pinch points

### Step 7.10: Final Electrical Check

Use multimeter to verify:
- [ ] No shorts between power and ground
- [ ] 12V present at motor driver input
- [ ] 5V present at buck converter output (within 5%)
- [ ] All grounds connected
- [ ] Correct polarity everywhere

---

## Phase 8: Software Setup

**Time estimate:** 2-4 hours

### Step 8.1: Mac Mini Setup

1. Complete macOS initial setup
2. Install Homebrew:
   ```bash
   /bin/bash -c "$(curl -fsSL https://raw.githubusercontent.com/Homebrew/install/HEAD/install.sh)"
   ```
3. Install essentials:
   ```bash
   xcode-select --install
   brew install python git node
   ```

### Step 8.2: Install OpenClaw

Follow OpenClaw docs for installation. Verify:
```bash
openclaw status
```

### Step 8.3: Arduino/ESP32 Firmware

**Motor control firmware features:**
- Serial command protocol (from Mac Mini)
- PWM motor speed control
- Encoder feedback (if equipped)
- Servo control for pan-tilt
- LED matrix driver
- Battery voltage reporting
- Emergency stop input

Flash firmware using Arduino IDE or PlatformIO.

**Test serial communication:**
```python
import serial
ser = serial.Serial('/dev/tty.usbmodemXXXX', 115200)
ser.write(b'PING\n')
print(ser.readline())  # Should return "PONG"
```

### Step 8.4: Camera Setup

**OAK-D Lite:**
```bash
pip install depthai
python -c "import depthai; print(depthai.__version__)"
```

Test:
```bash
python -m depthai_viewer
```

**USB Cameras:**
```bash
# List available cameras
ffmpeg -f avfoundation -list_devices true -i ""
```

### Step 8.5: Arm Setup

Verify LeRobot sees both arms:
```bash
python3 ~/.openclaw/skills/lerobot/scripts/arm.py ports
```

Home both arms:
```bash
python3 ~/.openclaw/skills/lerobot/scripts/arm.py home --type follower --port /dev/tty.usbmodemXXXX
```

### Step 8.6: Audio Setup

Test speaker:
```bash
say "Hello, I am Ren"
```

Test microphone (record and playback):
```bash
# Record
ffmpeg -f avfoundation -i ":0" -t 5 test_mic.wav
# Play
afplay test_mic.wav
```

### Step 8.7: Create System Test Script

```python
#!/usr/bin/env python3
"""Ren System Test - Run after assembly"""

import subprocess
import time

def test_motors():
    print("Testing motors...")
    # Send test commands via serial
    # Motors should spin briefly
    pass

def test_arms():
    print("Testing arms...")
    # Home each arm, do small movement
    pass

def test_cameras():
    print("Testing cameras...")
    # Capture frame from each camera
    pass

def test_head():
    print("Testing head pan-tilt...")
    # Sweep pan, then tilt
    pass

def test_display():
    print("Testing face display...")
    # Show test pattern
    pass

def test_audio():
    print("Testing audio...")
    subprocess.run(["say", "Audio test complete"])

def test_all():
    tests = [
        ("Motors", test_motors),
        ("Arms", test_arms),
        ("Cameras", test_cameras),
        ("Head", test_head),
        ("Display", test_display),
        ("Audio", test_audio),
    ]
    
    results = []
    for name, func in tests:
        try:
            func()
            results.append((name, "PASS"))
        except Exception as e:
            results.append((name, f"FAIL: {e}"))
    
    print("\n" + "="*40)
    print("TEST RESULTS")
    print("="*40)
    for name, result in results:
        print(f"  {name}: {result}")

if __name__ == "__main__":
    test_all()
```

---

## Testing & Calibration

### Motor Calibration

1. **Prop robot up** so tracks don't touch ground
2. **Test each motor:**
   - Forward command → wheel spins forward?
   - Speed control smooth?
3. **Test both together:**
   - Forward: both same direction/speed
   - Turn: differential speed
4. **On ground test:**
   - Straight line drive
   - Adjust trim if veering

### Arm Calibration

1. Run LeRobot calibration for each arm
2. Set joint limits to avoid body collision
3. Test workspace coverage

### Camera Calibration

1. OAK-D depth calibration (if needed)
2. Verify stereo alignment
3. Test depth at known distances

### Head Calibration

1. Find pan/tilt center positions
2. Set software limits
3. Tune acceleration for smooth movement

### Balance Check

1. Place robot on floor
2. Check for tipping tendency
3. Add ballast if unstable (mount in base)

---

## Troubleshooting

### Printing Issues

| Problem | Cause | Solution |
|---|---|---|
| Warping | Bed adhesion | Use brim, increase bed temp |
| Layer separation | Temp too low | Increase nozzle temp 5-10°C |
| Stringing | Retraction | Tune retraction settings |
| Parts don't fit | Shrinkage | Scale up 0.5-1% or sand |
| Holes too small | Horizontal expansion | Drill out or adjust in slicer |

### Assembly Issues

| Problem | Cause | Solution |
|---|---|---|
| Sections don't align | Warping/tolerance | Sand mating surfaces, use clamps |
| Inserts pull out | Not seated | Re-seat with more heat |
| Spine wobbles | Loose joints | Tighten connectors, check rods |
| Arms don't fit | Mount tolerance | Test print mount first |

### Motor Issues

| Problem | Cause | Solution |
|---|---|---|
| No spin | No power | Check battery, fuses, wiring |
| Wrong direction | Wiring | Swap motor leads |
| Jerky motion | PWM | Check driver, tune PWM frequency |
| Tracks slip | Tension | Adjust idler position |

### Electronics Issues

| Problem | Cause | Solution |
|---|---|---|
| No 5V | Buck converter | Check input, adjust pot |
| USB not detected | Power/cable | Try different port/cable |
| Servos jitter | Noise/power | Add capacitor, separate power |
| Interference | Grounding | Verify common ground |

---

## Maintenance Schedule

### Weekly
- [ ] Check track tension
- [ ] Inspect cable routing for wear
- [ ] Clean camera lenses
- [ ] Verify battery health

### Monthly
- [ ] Check all bolts for tightness
- [ ] Inspect printed parts for cracks
- [ ] Clean dust from electronics
- [ ] Backup configuration files

### As Needed
- [ ] Replace worn tracks
- [ ] Reprint damaged parts
- [ ] Update firmware/software
- [ ] Recalibrate if accuracy drifts

---

## Quick Reference

### Bolt Torque (approximate, for plastic)
- M3: Finger tight + 1/4 turn
- M4: Finger tight + 1/2 turn
- Don't overtighten! Plastic strips easily.

### Wire Colors (suggested standard)
- **Red:** +12V
- **Orange:** +5V
- **Black:** Ground
- **Blue:** Motor/servo signals
- **Green:** Sensor signals
- **White:** Data (I2C, serial)

### Emergency Stop
Always have a way to cut power quickly:
- Main switch accessible
- Consider adding E-stop button
- Know how to kill software

---

*Assembly guide version 2.0 (3D Printed) — 2026-02-04*
*Print well, build carefully, have fun!*

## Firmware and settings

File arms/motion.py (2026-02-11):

#!/usr/bin/env python3
"""
Smooth Motion Planning for SO-101 Robot Arms
Provides interpolated trajectories and velocity profiling.
"""

import os
import time
import math
from dataclasses import dataclass
from typing import Dict, List, Optional, Tuple
import scservo_sdk as sdk

# Servo control table addresses
ADDR_TORQUE_ENABLE = 40
ADDR_GOAL_POSITION = 42
ADDR_PRESENT_POSITION = 56
ADDR_MOVING_SPEED = 46
ADDR_PRESENT_SPEED = 58
ADDR_PRESENT_LOAD = 60

# Joint configuration
JOINTS = ["shoulder_pan", "shoulder_lift", "elbow_flex", "wrist_flex", "wrist_roll", "gripper"]
JOINT_IDS = {name: i+1 for i, name in enumerate(JOINTS)}

# Default limits (in servo units 0-4095, ~0-360°)
DEFAULT_LIMITS = {
    "shoulder_pan": (500, 3500),
    "shoulder_lift": (500, 3500),
    "elbow_flex": (500, 3500),
    "wrist_flex": (500, 3500),
    "wrist_roll": (500, 3500),
    "gripper": (1000, 3000),
}

# Default movement speed (0-1023, 0=max). 250 is smooth but purposeful.
DEFAULT_SPEED = 250

@dataclass
class ArmState:
    """Current state of all joints"""
    positions: Dict[str, int]  # Raw servo positions (0-4095)
    velocities: Optional[Dict[str, int]] = None
    loads: Optional[Dict[str, int]] = None
    timestamp: float = 0.0

class SmoothMotion:
    """
    Smooth motion controller for robot arms.
    Implements trajectory interpolation and velocity profiling.
    """
    
    def __init__(self, port: str, baudrate: int = 1000000):
        self.port = port
        self.baudrate = baudrate
        self.port_handler = None
        self.packet_handler = None
        self.connected = False
        self.joint_limits = DEFAULT_LIMITS.copy()
        
    def connect(self) -> bool:
        """Connect to the arm"""
        self.port_handler = sdk.PortHandler(self.port)
        self.packet_handler = sdk.PacketHandler(0)
        
        if not self.port_handler.openPort():
            print(f"Failed to open port {self.port}")
            return False
        
        self.port_handler.setBaudRate(self.baudrate)
        self.connected = True
        return True
    
    def disconnect(self):
        """Disconnect from the arm"""
        if self.port_handler:
            self.port_handler.closePort()
        self.connected = False
    
    def read_state(self) -> ArmState:
        """Read current state of all joints"""
        positions = {}
        for name, servo_id in JOINT_IDS.items():
            pos, result, _ = self.packet_handler.read2ByteTxRx(
                self.port_handler, servo_id, ADDR_PRESENT_POSITION
            )
            if result == sdk.COMM_SUCCESS:
                positions[name] = pos
        
        return ArmState(positions=positions, timestamp=time.time())
    
    def set_torque(self, enable: bool, joints: List[str] = None):
        """Enable/disable torque on joints"""
        joints = joints or JOINTS
        value = 1 if enable else 0
        for name in joints:
            self.packet_handler.write1ByteTxRx(
                self.port_handler, JOINT_IDS[name], ADDR_TORQUE_ENABLE, value
            )
    
    def set_speed(self, speed: int, joints: List[str] = None):
        """Set movement speed for joints (0-1023, 0=max)"""
        joints = joints or JOINTS
        for name in joints:
            self.packet_handler.write2ByteTxRx(
                self.port_handler, JOINT_IDS[name], ADDR_MOVING_SPEED, speed
            )
    
    def _clamp_position(self, joint: str, position: int) -> int:
        """Clamp position to joint limits"""
        min_pos, max_pos = self.joint_limits.get(joint, (0, 4095))
        return max(min_pos, min(max_pos, position))
    
    def move_joint(self, joint: str, position: int, speed: int = 300):
        """Move a single joint to position"""
        position = self._clamp_position(joint, position)
        servo_id = JOINT_IDS[joint]
        
        self.packet_handler.write2ByteTxRx(
            self.port_handler, servo_id, ADDR_MOVING_SPEED, speed
        )
        self.packet_handler.write2ByteTxRx(
            self.port_handler, servo_id, ADDR_GOAL_POSITION, position
        )
    
    def move_joints(self, positions: Dict[str, int], speed: int = 300):
        """Move multiple joints simultaneously"""
        for joint, position in positions.items():
            self.move_joint(joint, position, speed)
    
    # ==================== RECOMMENDED API ====================
    
    def move_to(self, positions: Dict[str, int], speed: int = None, wait: float = None):
        """
        Move to target positions using servo's native motion control.
        This is the recommended way to move - smooth and efficient.
        
        Args:
            positions: Target positions for joints (servo units 0-4095)
            speed: Movement speed (0-1023, 0=max). Default: DEFAULT_SPEED (250)
            wait: Optional seconds to wait after sending command.
                  If None, estimates based on distance and speed.
        """
        speed = speed if speed is not None else DEFAULT_SPEED
        self.move_joints(positions, speed=speed)
        
        if wait is not None:
            time.sleep(wait)
        else:
            # Estimate wait time based on max distance and speed
            current = self.read_state().positions
            max_dist = 0
            for joint, target in positions.items():
                if joint in current:
                    dist = abs(target - current[joint])
                    max_dist = max(max_dist, dist)
            # Rough estimate: speed 250 moves ~500 units/sec
            estimated_time = (max_dist / 500) * (250 / max(speed, 1)) + 0.1
            time.sleep(min(estimated_time, 3.0))  # Cap at 3 seconds
    
    def go_home(self, speed: int = None):
        """Move all joints to center position (2048)"""
        home = {joint: 2048 for joint in JOINTS}
        self.move_to(home, speed=speed)
    
    # ==================== SMOOTH MOTION (LEGACY) ====================
    
    def linear_interpolate(
        self, 
        start: Dict[str, int], 
        end: Dict[str, int], 
        steps: int
    ) -> List[Dict[str, int]]:
        """
        Generate linear interpolation between two positions.
        Returns list of intermediate positions.
        """
        trajectory = []
        for i in range(steps + 1):
            t = i / steps
            point = {}
            for joint in JOINTS:
                if joint in start and joint in end:
                    point[joint] = int(start[joint] + t * (end[joint] - start[joint]))
            trajectory.append(point)
        return trajectory
    
    def cubic_interpolate(
        self,
        start: Dict[str, int],
        end: Dict[str, int],
        steps: int
    ) -> List[Dict[str, int]]:
        """
        Generate cubic (ease-in-out) interpolation.
        Smoother acceleration/deceleration at endpoints.
        """
        trajectory = []
        for i in range(steps + 1):
            # Cubic ease-in-out: t' = 3t² - 2t³
            t = i / steps
            t_smooth = 3 * t * t - 2 * t * t * t
            
            point = {}
            for joint in JOINTS:
                if joint in start and joint in end:
                    point[joint] = int(start[joint] + t_smooth * (end[joint] - start[joint]))
            trajectory.append(point)
        return trajectory
    
    def trapezoidal_velocity(
        self,
        start: Dict[str, int],
        end: Dict[str, int],
        steps: int,
        accel_fraction: float = 0.25
    ) -> List[Dict[str, int]]:
        """
        Generate trapezoidal velocity profile.
        - Accelerates for first accel_fraction of motion
        - Constant velocity in middle
        - Decelerates for last accel_fraction of motion
        """
        trajectory = []
        accel_steps = int(steps * accel_fraction)
        
        for i in range(steps + 1):
            if i < accel_steps:
                # Acceleration phase: quadratic ramp
                t = 0.5 * (i / accel_steps) ** 2 * accel_fraction
            elif i > steps - accel_steps:
                # Deceleration phase
                remaining = (steps - i) / accel_steps
                t = 1.0 - 0.5 * remaining ** 2 * accel_fraction
            else:
                # Constant velocity phase
                t = accel_fraction / 2 + (i - accel_steps) / (steps - 2 * accel_steps) * (1 - accel_fraction)
            
            point = {}
            for joint in JOINTS:
                if joint in start and joint in end:
                    point[joint] = int(start[joint] + t * (end[joint] - start[joint]))
            trajectory.append(point)
        
        return trajectory
    
    def execute_trajectory(
        self,
        trajectory: List[Dict[str, int]],
        dt: float = 0.02,
        speed: int = 0  # 0 = max speed (servo handles timing)
    ):
        """
        Execute a trajectory by sending waypoints at regular intervals.
        
        Args:
            trajectory: List of position dictionaries
            dt: Time between waypoints (seconds)
            speed: Servo speed setting (0=max, let dt control timing)
        """
        self.set_torque(True)
        self.set_speed(speed)
        
        for waypoint in trajectory:
            for joint, position in waypoint.items():
                position = self._clamp_position(joint, position)
                self.packet_handler.write2ByteTxRx(
                    self.port_handler, 
                    JOINT_IDS[joint], 
                    ADDR_GOAL_POSITION, 
                    position
                )
            time.sleep(dt)
    
    def smooth_move(
        self,
        target: Dict[str, int],
        duration: float = 1.0,
        profile: str = "cubic"
    ):
        """
        High-level smooth move to target position.
        
        Args:
            target: Target positions for joints
            duration: Total movement time (seconds)
            profile: Interpolation profile ("linear", "cubic", "trapezoidal")
        """
        current = self.read_state()
        
        # Calculate steps based on duration (50Hz update rate)
        steps = max(int(duration * 50), 10)
        dt = duration / steps
        
        # Generate trajectory
        if profile == "linear":
            trajectory = self.linear_interpolate(current.positions, target, steps)
        elif profile == "cubic":
            trajectory = self.cubic_interpolate(current.positions, target, steps)
        elif profile == "trapezoidal":
            trajectory = self.trapezoidal_velocity(current.positions, target, steps)
        else:
            raise ValueError(f"Unknown profile: {profile}")
        
        # Execute
        self.execute_trajectory(trajectory, dt=dt, speed=0)
    
    def wave(self, joint: str = "wrist_roll", amplitude: int = 400, cycles: int = 3, period: float = 0.5):
        """Do a wave motion on a joint"""
        current = self.read_state()
        center = current.positions.get(joint, 2048)
        
        self.set_torque(True, [joint])
        self.set_speed(400, [joint])
        
        steps_per_cycle = int(period * 50)
        
        for cycle in range(cycles):
            for i in range(steps_per_cycle):
                t = i / steps_per_cycle
                offset = int(amplitude * math.sin(2 * math.pi * t))
                self.move_joint(joint, center + offset)
                time.sleep(period / steps_per_cycle)
        
        # Return to center
        self.move_joint(joint, center)
        time.sleep(0.3)
        self.set_torque(False, [joint])

class DualArmController:
    """Controller for synchronized dual-arm movements"""
    
    def __init__(self, leader_port: str, follower_port: str):
        self.leader = SmoothMotion(leader_port)
        self.follower = SmoothMotion(follower_port)
    
    def connect(self) -> bool:
        return self.leader.connect() and self.follower.connect()
    
    def disconnect(self):
        self.leader.disconnect()
        self.follower.disconnect()
    
    def mirror_move(self, target: Dict[str, int], duration: float = 1.0):
        """Move both arms to same position (mirrored)"""
        import threading
        
        def move_arm(arm, target):
            arm.smooth_move(target, duration=duration)
        
        t1 = threading.Thread(target=move_arm, args=(self.leader, target))
        t2 = threading.Thread(target=move_arm, args=(self.follower, target))
        
        t1.start()
        t2.start()
        t1.join()
        t2.join()
    
    def synchronized_wave(self, cycles: int = 3):
        """Both arms wave together"""
        import threading
        
        t1 = threading.Thread(target=self.leader.wave, kwargs={"cycles": cycles})
        t2 = threading.Thread(target=self.follower.wave, kwargs={"cycles": cycles})
        
        t1.start()
        t2.start()
        t1.join()
        t2.join()

# Example usage and testing
if __name__ == "__main__":
    import json
    
    # Load config
    config_path = os.path.expanduser("~/.openclaw/skills/lerobot/config.json")
    with open(config_path) as f:
        config = json.load(f)
    
    leader_port = config["leader"]["port"].replace("tty.", "cu.")
    follower_port = config["follower"]["port"].replace("tty.", "cu.")
    
    print("Testing Motion Controller")
    print(f"Leader: {leader_port}")
    print(f"Follower: {follower_port}")
    print(f"Default speed: {DEFAULT_SPEED}")
    
    # Test single arm
    arm = SmoothMotion(follower_port)
    if arm.connect():
        print("\nConnected to follower arm")
        
        state = arm.read_state()
        home = state.positions.copy()
        print(f"Home positions: {home}")
        
        arm.set_torque(True)
        
        # Test move_to (recommended API)
        print("\nTesting move_to (native servo motion)...")
        target = home.copy()
        target["shoulder_pan"] = min(home.get("shoulder_pan", 2048) + 400, 3000)
        arm.move_to(target)
        
        target["shoulder_pan"] = max(home.get("shoulder_pan", 2048) - 400, 1000)
        arm.move_to(target)
        
        # Return home
        print("Returning home...")
        arm.move_to(home)
        
        arm.set_torque(False)
        arm.disconnect()
        print("Done!")
    else:
        print("Failed to connect")

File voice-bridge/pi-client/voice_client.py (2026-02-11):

#!/usr/bin/env python3
"""
Voice Bridge Client - Raspberry Pi Zero with Codec Zero
Push-to-talk voice interface to Ren on Mac Mini.

Hardware:
- Raspberry Pi Zero (W/2W)
- Codec Zero I2S Audio HAT
- Wired earbuds with mic
- Push-to-talk button on GPIO

Wiring:
- PTT Button: GPIO17 to GND (internal pull-up, active low)
- LED (optional): GPIO27 for status indication
"""

import os
import sys
import time
import wave
import struct
import tempfile
import requests
from pathlib import Path

# Configuration
SERVER_URL = os.environ.get("VOICE_SERVER", "http://macmini.local:5555")
SAMPLE_RATE = 16000  # 16kHz for Whisper
CHANNELS = 1  # Mono
SAMPLE_WIDTH = 2  # 16-bit
PTT_GPIO = 17  # Push-to-talk button
LED_GPIO = 27  # Status LED (optional)
AUDIO_DEVICE = "default"  # ALSA device

# Check if we're on a Pi with GPIO
try:
    import RPi.GPIO as GPIO
    HAS_GPIO = True
except ImportError:
    HAS_GPIO = False
    print("Warning: RPi.GPIO not available, using keyboard input")

# Check for pyaudio
try:
    import pyaudio
    HAS_PYAUDIO = True
except ImportError:
    HAS_PYAUDIO = False
    print("Warning: pyaudio not available, using arecord/aplay")

class VoiceClient:
    def __init__(self, server_url=SERVER_URL):
        self.server_url = server_url
        self.recording = False
        self.audio_buffer = []
        
        if HAS_GPIO:
            self._setup_gpio()
        
        if HAS_PYAUDIO:
            self.audio = pyaudio.PyAudio()
    
    def _setup_gpio(self):
        """Setup GPIO for PTT button and LED"""
        GPIO.setmode(GPIO.BCM)
        GPIO.setup(PTT_GPIO, GPIO.IN, pull_up_down=GPIO.PUD_UP)
        GPIO.setup(LED_GPIO, GPIO.OUT)
        GPIO.output(LED_GPIO, GPIO.LOW)
        
        # Add edge detection for button
        GPIO.add_event_detect(
            PTT_GPIO, 
            GPIO.BOTH, 
            callback=self._button_callback,
            bouncetime=50
        )
    
    def _button_callback(self, channel):
        """Handle PTT button press/release"""
        if GPIO.input(PTT_GPIO) == GPIO.LOW:
            # Button pressed
            self._start_recording()
        else:
            # Button released
            self._stop_recording()
    
    def _led_on(self):
        if HAS_GPIO:
            GPIO.output(LED_GPIO, GPIO.HIGH)
    
    def _led_off(self):
        if HAS_GPIO:
            GPIO.output(LED_GPIO, GPIO.LOW)
    
    def _start_recording(self):
        """Start recording audio"""
        if self.recording:
            return
        
        print("🎤 Recording...")
        self._led_on()
        self.recording = True
        self.audio_buffer = []
        
        if HAS_PYAUDIO:
            self._record_pyaudio()
    
    def _stop_recording(self):
        """Stop recording and process"""
        if not self.recording:
            return
        
        print("⏹️ Processing...")
        self.recording = False
        self._led_off()
    
    def _record_pyaudio(self):
        """Record using PyAudio (runs in thread)"""
        import threading
        
        def record_thread():
            stream = self.audio.open(
                format=pyaudio.paInt16,
                channels=CHANNELS,
                rate=SAMPLE_RATE,
                input=True,
                frames_per_buffer=1024
            )
            
            while self.recording:
                data = stream.read(1024, exception_on_overflow=False)
                self.audio_buffer.append(data)
            
            stream.stop_stream()
            stream.close()
        
        thread = threading.Thread(target=record_thread)
        thread.start()
    
    def record_with_arecord(self, duration=None):
        """Record using arecord (ALSA) - blocking"""
        with tempfile.NamedTemporaryFile(suffix=".wav", delete=False) as f:
            temp_path = f.name
        
        cmd = [
            "arecord",
            "-D", AUDIO_DEVICE,
            "-f", "S16_LE",
            "-r", str(SAMPLE_RATE),
            "-c", str(CHANNELS),
            "-t", "wav",
        ]
        
        if duration:
            cmd.extend(["-d", str(duration)])
        
        cmd.append(temp_path)
        
        import subprocess
        subprocess.run(cmd, check=True)
        
        return temp_path
    
    def play_audio(self, audio_path):
        """Play audio file through earbuds"""
        if HAS_PYAUDIO:
            self._play_pyaudio(audio_path)
        else:
            self._play_aplay(audio_path)
    
    def _play_pyaudio(self, audio_path):
        """Play using PyAudio"""
        wf = wave.open(audio_path, 'rb')
        
        stream = self.audio.open(
            format=self.audio.get_format_from_width(wf.getsampwidth()),
            channels=wf.getnchannels(),
            rate=wf.getframerate(),
            output=True
        )
        
        chunk = 1024
        data = wf.readframes(chunk)
        while data:
            stream.write(data)
            data = wf.readframes(chunk)
        
        stream.stop_stream()
        stream.close()
        wf.close()
    
    def _play_aplay(self, audio_path):
        """Play using aplay (ALSA)"""
        import subprocess
        subprocess.run(["aplay", "-D", AUDIO_DEVICE, audio_path], check=True)
    
    def save_buffer_to_wav(self):
        """Save recorded buffer to WAV file"""
        if not self.audio_buffer:
            return None
        
        with tempfile.NamedTemporaryFile(suffix=".wav", delete=False) as f:
            temp_path = f.name
        
        with wave.open(temp_path, 'wb') as wf:
            wf.setnchannels(CHANNELS)
            wf.setsampwidth(SAMPLE_WIDTH)
            wf.setframerate(SAMPLE_RATE)
            wf.writeframes(b''.join(self.audio_buffer))
        
        return temp_path
    
    def send_to_server(self, audio_path):
        """Send audio to server, get response audio"""
        print(f"📤 Sending to {self.server_url}...")
        
        try:
            with open(audio_path, 'rb') as f:
                response = requests.post(
                    f"{self.server_url}/voice",
                    files={"audio": ("recording.wav", f, "audio/wav")},
                    timeout=30
                )
            
            if response.status_code == 200:
                # Save response audio
                with tempfile.NamedTemporaryFile(suffix=".wav", delete=False) as f:
                    f.write(response.content)
                    return f.name
            else:
                print(f"Server error: {response.status_code}")
                return None
                
        except requests.exceptions.RequestException as e:
            print(f"Network error: {e}")
            return None
    
    def voice_interaction(self, audio_path):
        """Full voice interaction cycle"""
        response_audio = self.send_to_server(audio_path)
        
        if response_audio:
            print("🔊 Playing response...")
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

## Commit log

2026-02-11 Initial commit: Ren robot body project
    - FreeCAD and Blender models
    - STL files for printing
    - Assembly guide
    - Parts lists
    - Voice bridge project
    [Arm_Mount_Left.stl, Arm_Mount_Left_Detailed.stl, Arm_Mount_Right.stl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]
2026-02-15 Add arm control scripts and training data
